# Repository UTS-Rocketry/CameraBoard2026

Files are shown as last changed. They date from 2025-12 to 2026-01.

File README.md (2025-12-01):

# CameraBoard – UTS Rocketry Avionics
High-reliability camera control and downlink board built around the **STM32F405RGT6**, designed for UTS Rocketry’s flight avionics stack.  
The board provides **camera power switching**, **camera UART control**, **video downlink support**, and **CAN-based communication** with the central avionics system.

---

## Project Overview
The CameraBoard is a custom PCB designed to interface action cameras with the UTS Rocketry avionics system.  
It provides:

- **Reliable power delivery** to the camera through a load-switch architecture  
- **UART-based camera control** (start/stop recording, mode switching, etc.)  
- **Video downlink support** (placeholder until RF/video module is finalised)  
- **CAN Bus** connectivity for inter-module communication  
- **Debug UART** and activity LEDs  
- **5V → 3.3V power tree** and full onboard decoupling network  

Built around the **STM32F405RGT6**, chosen for performance, CAN support, and strong STM32 ecosystem compatibility.

---

## Key Features
- **STM32F405RGT6 MCU**
- **Camera Power Switching**
  - Load switch controlled via GPIO  
  - Local decoupling + bulk capacitance
- **Camera Control (UART)**
  - Compatible with RunCam-style UART protocols
- **CAN Bus Interface**
  - TX/RX routed to CAN transceiver  
  - Interfaces with the main flight computer
- **Video Downlink Support**
  - Reserved connector footprint  
  - Pins allocated for future video transmitter module
- **Debug Interface**
  - UART for logging  
  - Status, power, and activity LEDs
- **Power Topology**
  - Headers for 5V buck converters  
  - 3.3V rail for MCU and logic  
  - Full decoupling network following ST guidelines

---
## Current Project Status
Stage: End of Schematic Design

## Contributors
Reed Basangan — Software Lead, UTS Rocketry
UTS Rocketry Avionics Team

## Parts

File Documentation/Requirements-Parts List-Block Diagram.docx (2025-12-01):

# Camera PCB Design

# Project context

- Record stable HD footage throughout the flight
- Fit within the avionics bay
- Store video locally and stream live video to the ground station
- Triggered by an STM32 that will receive directions from the main flight computer using the CAN protocol
- STM32 triggers recording
- Runcam Split handles video capture and storage.

# Functional Requirements

### Video

- Record 720p–1080p video at 30 fps (60 fps optional).
- Use RunCam Split-style cameras with onboard H.264 encoding to MP4.
- Each camera saves video to a high-endurance microSD card (≥ 32 GB).
- Support two to three cameras controlled by the STM32.
- Provide an optional analog video output for live FPV feed.

### Control and Feedback

- STM32 sends start/stop triggers to each camera via GPIO or UART.
- Cameras provide status signals (idle, recording, fault) to the STM32.
- MCU can power-cycle each camera through dedicated load switches.
- MCU broadcasts camera status and events over the CAN bus (1 Mbps).
- Optional UART link for VTX channel and power control (SmartAudio or Tramp).

### Power System

- Operates from a 9–16 V DC input.
- Includes a buck converter to 5 V (≥ 3 A) and an LDO regulator to 3.3 V for logic.
- LC filters on each camera and VTX power rail to reduce noise.
- Reverse-polarity, surge, and ESD protection on the power input.
- Hold-up capacitance to prevent resets during short power dips.

### Processing and Communication

- Main MCU: STM32F405 or STM32F407 with bxCAN.
- CAN transceiver: TI SN65HVD230D / DR.
- Communicates with other avionics via Classical CAN 2.0B at 1 Mbps.
- Supports I²C or SPI sensors for temperature, voltage, and IMU data.
- Real-time clock for timestamps and synchronised flight event logging.

### Data and Logging

- Logs temperature, supply voltage, and system health every few seconds.
- Stores log data to onboard flash or SD card.
- Records key events such as liftoff, apogee, and recording start/stop with timestamps.

### Reliability and Safety

- Watchdog timer resets the MCU on a fault.
- Automatic recovery from camera or power faults.
- Designed to withstand 15 g vibration, 50 g shock, and –10 °C to +60 °C operation.
- Uses locking connectors and strain-relieved wiring.
- Includes TVS diodes and a resettable fuse on main power input.

### Live Video Feed (Optional)

- Supports 5.8 GHz analog VTX for real-time ground video.
- VTX is powered and controlled by the STM32.
- Target latency below 50 ms.

# Parts selection (Pending Availability)

- Microprocesser: STM32F405RG or STM32F407VGT6
  - bxCAN (Classical CAN 2.0A/B, up to 1 Mbps)
- Camera Board: 2 -3 RunCam Split HD
- Can Transevier: TI SN65HVD230D / DR? (This is just the first one that came up, so it can be changed)
- PCB Parts: TBD, as I will need more guidance and look at parts availability
- Video Transmitter: FPV drone transmitter (5.8ghz)

# Architecture

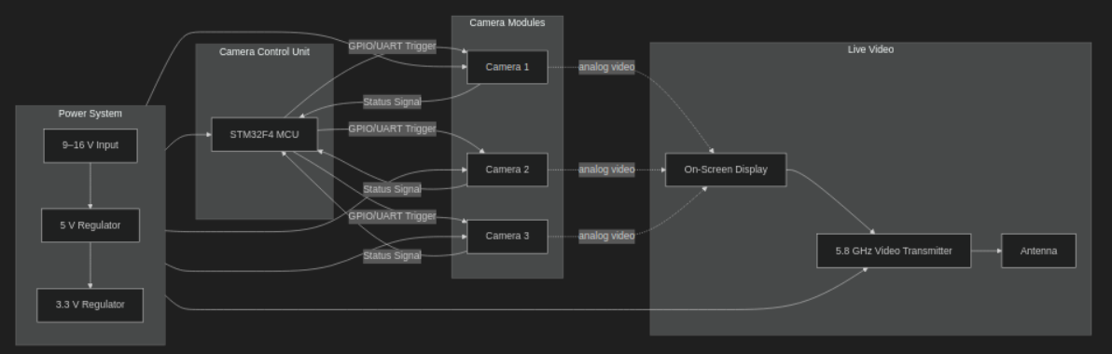
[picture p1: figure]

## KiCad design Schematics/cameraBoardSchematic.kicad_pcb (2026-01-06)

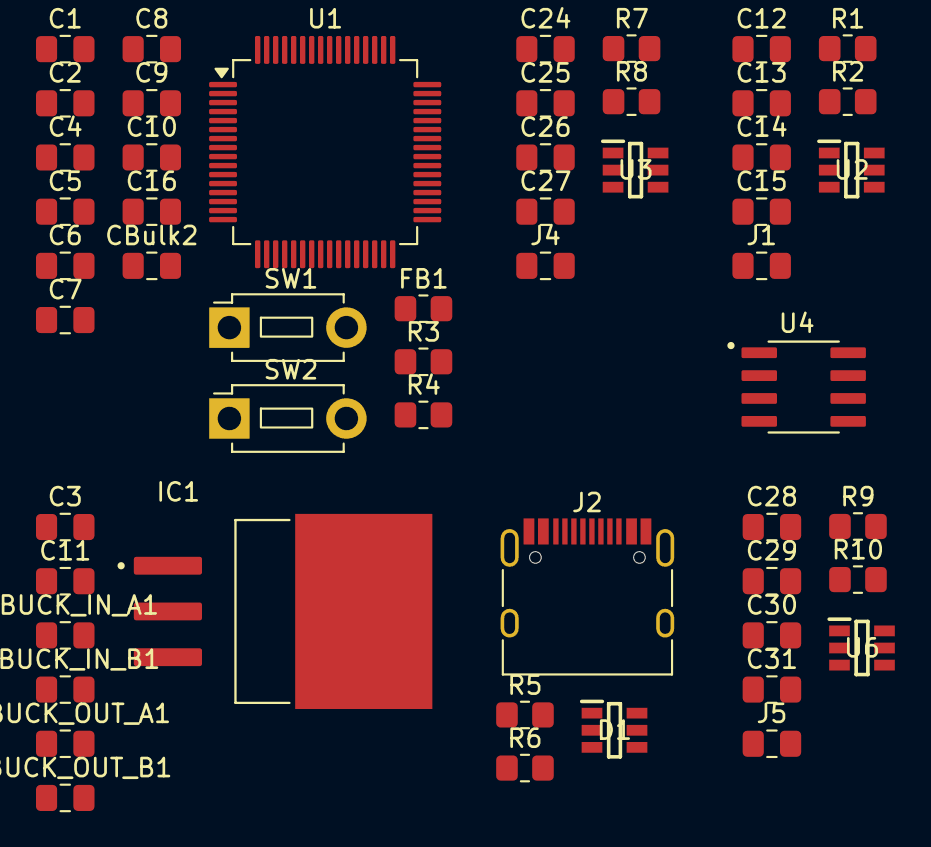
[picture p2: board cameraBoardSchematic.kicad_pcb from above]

Board: 2 copper layers, 53 parts (0 on the bottom side), 23 nets, no tracks yet.

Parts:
C1, C2, C4, C5, C6, C16: 100nf; C_0805_2012Metric_Pad1.18x1.45mm_HandSolder
C3: .47u; C_0805_2012Metric_Pad1.18x1.45mm_HandSolder
C7, C8: 2.2u; C_0805_2012Metric_Pad1.18x1.45mm_HandSolder
C9, C12, C14, C24, C25, C28, C29: 1u; C_0805_2012Metric_Pad1.18x1.45mm_HandSolder
C10: 10u; C_0805_2012Metric_Pad1.18x1.45mm_HandSolder
C11: 33u; C_0805_2012Metric_Pad1.18x1.45mm_HandSolder
C13, C26, C30: 47u; C_0805_2012Metric_Pad1.18x1.45mm_HandSolder
C15, C27, C31: .1u; C_0805_2012Metric_Pad1.18x1.45mm_HandSolder
CBulk2: 4.7u; C_0805_2012Metric_Pad1.18x1.45mm_HandSolder
D1: SRV05-4.TCT; SOT95P280X145-6N
FB1: FerriteBead; R_0805_2012Metric_Pad1.20x1.40mm_HandSolder
IC1: LM3940IS-3.3_NOPB; TO254P1524X483-4N
J1, J4, J5: Runcam Split 4 v2; C_0805_2012Metric_Pad1.18x1.45mm_HandSolder
J2: USB_C_Receptacle; USB_C_Receptacle_HRO_TYPE-C-31-M-12
J_BUCK_IN_A1: C_0805_2012Metric_Pad1.18x1.45mm_HandSolder
J_BUCK_IN_B1: C_0805_2012Metric_Pad1.18x1.45mm_HandSolder
J_BUCK_OUT_A1: C_0805_2012Metric_Pad1.18x1.45mm_HandSolder
J_BUCK_OUT_B1: C_0805_2012Metric_Pad1.18x1.45mm_HandSolder
R1: 22k; R_0805_2012Metric_Pad1.20x1.40mm_HandSolder
R2, R3, R7, R9: 100k; R_0805_2012Metric_Pad1.20x1.40mm_HandSolder
R4: 10k; R_0805_2012Metric_Pad1.20x1.40mm_HandSolder
R5, R6: 5.1k; R_0805_2012Metric_Pad1.20x1.40mm_HandSolder
R8, R10: 1k; R_0805_2012Metric_Pad1.20x1.40mm_HandSolder
SW1, SW2: SW_Push; SW_PUSH_1P1T_6x3.5mm_H5.0_APEM_MJTP1250
U1: STM32F405RGTx; LQFP-64_10x10mm_P0.5mm
U2, U3, U6: TPS22917DBVR; SOT95P280X145-6N
U4: SN65HVD230DR; SOIC127P599X175-8N

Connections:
+3.3V: C1.1, C2.1, C4.1, C5.1, C6.1, C11.1, CBulk2.1, FB1.1, IC1.3 (VOUT), R2.2, R4.1, R7.2, R9.2, SW1.1, U1.1 (VBAT), U1.13 (VDDA), U1.19 (VDD), U1.32 (VDD), U1.48 (VDD), U1.64 (VDD)
+3.3VA: C9.2, C10.2, FB1.2
+5V: C3.1, C12.1, C24.1, C28.1, D1.5, IC1.1 (VIN), J2.A4 (VBUS), J2.A9 (VBUS), J2.B4 (VBUS), J2.B9 (VBUS), J_BUCK_OUT_A1.1, J_BUCK_OUT_B1.1, U2.1 (VIN), U3.1 (VIN), U6.1 (VIN)
/Camera_center/<NO NET>: C29.1, C30.1, C31.1, U6.5 (QOD), U6.6 (VOUT)
/Camera_center/CAM_C_PWN_EN: R9.1, U6.3 (ON)
/Camera_center/CAM_UART_TX: J5.1 (RX), R10.1
/Camera_left/<NO NET>: C13.1, C14.1, C15.1, U2.5 (QOD), U2.6 (VOUT)
/Camera_left/CAM_L_PWN_EN: R2.1, U2.3 (ON)
/Camera_left/CAM_UART_TX: J1.1 (RX), R1.1
/Camera_right/<NO NET>: C25.1, C26.1, C27.1, U3.5 (QOD), U3.6 (VOUT)
/Camera_right/CAM_R_PWN_EN: R7.1, U3.3 (ON)
/Camera_right/CAM_UART_TX: J4.1 (RX), R8.1
/MCU/BOOT0: R3.2, SW1.2, U1.60 (BOOT0)
/MCU/NRST: C16.1, R4.2, U1.7 (NRST)
/Power/VBAT: J_BUCK_IN_A1.1, J_BUCK_IN_B1.1
/usb_type_c/D+: D1.1, J2.A6 (D+), J2.B6 (D+)
/usb_type_c/D-: D1.3, J2.A7 (D-), J2.B7 (D-)
GND: C1.2, C2.2, C3.2, C4.2, C5.2, C6.2, C7.2, C8.2, C9.1, C10.1, C11.2, C12.2, C13.2, C14.2, C15.2, C24.2, C25.2, C26.2, C27.2, C28.2, C29.2, C30.2, C31.2, CBulk2.2, D1.2, IC1.2 (GND), J2.A1 (GND), J2.A12 (GND), J2.B1 (GND), J2.B12 (GND), J2.S1 (SHIELD), J_BUCK_IN_A1.2, J_BUCK_IN_B1.2, J_BUCK_OUT_A1.2, R1.2, R3.1, R5.2, R6.2, R8.2, R10.2, SW2.1, U1.12 (VSSA), U1.18 (VSS), U1.63 (VSS), U2.2 (GND), U3.2 (GND), U4.2 (GND), U4.8 (RS), U6.2 (GND)
unnamed: C16.2, SW2.2
unnamed: J2.A5 (CC1), R5.1
unnamed: J2.B5 (CC2), R6.1
unnamed: C7.1, U1.31 (VCAP_1)
unnamed: C8.1, U1.47 (VCAP_2)

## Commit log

2025-12-01 Add initial README for CameraBoard project
2025-12-08 added usb type C and changed to CAN2
    [MCU.kicad_sch, cameraBoardSchematic.kicad_sch, usb_type_c_sch.kicad_sch]
2025-12-10 finished LED one Power and one Programable
    [MCU.kicad_sch]
2026-01-06 assigned footprints ready for pcb design
    [Camera_center.kicad_sch, Camera_left.kicad_sch, Camera_right.kicad_sch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]
